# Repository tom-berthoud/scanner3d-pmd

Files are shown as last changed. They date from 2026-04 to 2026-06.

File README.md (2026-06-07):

# scanner3d-pmd

Scanner 3D à triangulation laser — Projet étudiant HEIG-VD, semestre 4, module PMD.

Le système capture des profils d'un objet en rotation sous un laser ligne, vu par deux caméras, reconstruit un nuage de points 3D, et exporte un fichier STL ou OBJ. Tout se passe dans une boîte fermée pilotée par un Raspberry Pi, accessible via une interface web ou un petit écran local.

## Rapport

La dernière version compilée du rapport est publiée automatiquement à chaque
push :
[télécharger le PDF](https://github.com/tom-berthoud/scanner3d-pmd/releases/download/rapport-latest/rapport-scanner3d-latest.pdf).

---

## Comment ça fonctionne

```
1. L'utilisateur pose l'objet sur le plateau et lance un scan
2. Le plateau tourne par pas réguliers sur 360° (nombre de photos = `scan.n_steps`, défaut 100)
3. À chaque pas : laser allumé → photo (les deux caméras) → laser éteint
4. Chaque image est analysée pour extraire la ligne laser verte
5. La triangulation géométrique convertit chaque ligne en profil 3D ; les deux
   vues réduisent les zones éclairées mais masquées
6. Tous les profils sont fusionnés en un nuage de points complet
7. Export en fichier STL ou OBJ, téléchargeable via l'interface web
```

**Géométrie de triangulation (deux caméras) :**
- Azimuts caméra/laser : ≈ −25° (caméra `right`) et +33° (caméra `left`)
- Élévations par rapport au plan XZ : ≈ −20° / +20°
- Plateau : centre à ≈ 400 mm des caméras (repère mm)
- Intrinsèques approximées (mode sans damier) : fx = fy ≈ 800 px @ 640×480 (facteur 1.25)

**Contraintes du projet :**
- Objets jusqu'à 150 × 150 × 150 mm
- Temps de scan < 10 min
- Prise en main < 10 min
- Budget ~300 CHF
- Boîte fermée (contrôle de la lumière ambiante)

---

## Structure du projet

```
scanner3d-pmd/
├── scanner/
│   ├── hardware/          Contrôle GPIO : moteur, laser, écran, caméra
│   │   └── mock.py        Simulation hardware (sans Raspberry Pi)
│   ├── acquisition/       Pipeline de capture image + sauvegarde frames
│   ├── calibration/       Calibration caméra et plan laser
│   ├── processing/        Extraction ligne laser + triangulation 3D
│   ├── reconstruction/    Fusion des profils en nuage de points
│   ├── export/            Génération STL / OBJ (Open3D Poisson)
│   ├── orchestration/     Machine d'états, boucle de scan
│   └── interface/         Serveur web Flask + affichage écran local
│       ├── templates/     Pages HTML (Jinja2)
│       └── static/        CSS, JS et assets vendorisés (vendor/ — hors-ligne)
├── config/                Paramètres YAML de scan et calibration
├── scripts/               Scripts utilitaires (ex. scanner-eng.sh)
├── tests/                 Tests unitaires et d'intégration
└── docs/                  Documentation, rapport et fichiers de fabrication
    ├── rapport/                 Rapport LaTeX (PDF compilé en Release)
    ├── cahier_des_charges/      Cahier des charges (LaTeX) + diagramme FAST
    ├── conception mécanique/    Modèles SolidWorks (.SLDPRT/.SLDASM),
    │                            DXF de découpe laser et STL d'impression 3D (CAD/)
    ├── schema/                  PCB et schéma électronique (KiCad)
    └── connection_procedure.md  Procédure de connexion PC ↔ Raspberry Pi
```

---

## Démarrage rapide

### Prérequis

- Python 3.11+
- Sur Raspberry Pi : Raspberry Pi OS 64-bit, deux caméras pour l'acquisition à
  double vue (Pi Camera Module 3 via CSI + caméra USB)

### Installation

```bash
git clone <repo-url>
cd scanner3d-pmd
python -m venv .venv && source .venv/bin/activate
pip install -r requirements.txt
```

> Les assets de l'interface (Bootstrap, polices, Three.js) sont **vendorisés**
> dans `scanner/interface/static/vendor/` : aucune connexion internet n'est
> requise au runtime, ni sur le PC, ni sur le Pi.

### Raccourcis (Makefile)

Un `Makefile` regroupe les opérations courantes. `make` (ou `make help`) liste
tout. Le Pi cible est `admin@192.168.55.1` (surchargeable :
`make ssh PI_HOST=…`).

| Catégorie | Commande | Effet |
|---|---|---|
| Local | `make install` / `make test` / `make test-fast` | venv + deps / tous les tests / tests rapides |
| Local | `make run` | lancer l'UI en **mode scan seul** (= prod) + navigateur |
| Local | `make run-full` | lancer l'UI avec **toutes les pages** (déverrouillé) + navigateur |
| Local | `make unlock-local` / `make lock-local` | (dé)verrouiller les pages techniques **en local** |
| Réseau | `make ping` / `make net-check` | Pi joignable / diagnostic réseau du Pi |
| Connexion | `make ssh` / `make open` | session SSH interactive / ouvrir l'UI du Pi dans le navigateur |
| Déploiement | `make pull` / `make pi-install` / `make pi-run` / `make pi-restart` | `git pull` / installer / lancer / redémarrer l'UI sur le Pi |
| Supervision | `make pi-status` / `make pi-logs` | état du service / logs sur le Pi |
| Ingénierie | `make unlock` / `make lock` / `make eng-status` | (dé)verrouiller les pages techniques **sur le Pi** (SSH) |

---

## Tester en local (sans Raspberry Pi — mode mock)

Le module `scanner/hardware/mock.py` simule tout le hardware et s'active
automatiquement si `gpiozero` n'est pas disponible (donc sur n'importe quel PC).

```bash
source .venv/bin/activate
python -m scanner.interface.web        # http://localhost:5000
```

Sur une machine de dev, débloquez d'emblée les pages d'ingénierie en mettant
`interface.engineering_force: true` dans `config/settings.yaml` (voir
[Mode ingénierie](#mode-ingénierie--accès-aux-pages-de-configuration)).

**Forme simulée** (`config/settings.yaml` → `camera.mock_shape`) : un seul
objet virtuel est disponible, un **`cube`** posé sur le plateau (demi-côté
30 mm, hauteur 60 mm).

Visualiser les images captées sans lancer un scan complet :
```
http://localhost:5000/preview                       ← slider interactif
http://localhost:5000/preview/frame?angle=0
http://localhost:5000/preview/extraction?angle=0    ← overlay ligne laser
```

**Tests :**
```bash
pytest tests/ -v                       # tous les tests
pytest tests/test_state_machine.py -v  # machine d'états seule (sans deps lourdes)
pytest tests/ -m integration           # tests nécessitant le vrai hardware
```

---

## Mise en production (Raspberry Pi)

1. **Connexion** PC ↔ Pi (Ethernet + SSH/HTTP) : voir
   [`docs/connection_procedure.md`](docs/connection_procedure.md).
2. **Installer** le projet et les dépendances (cf. *Installation* ci-dessus). Sur
   le Pi, `gpiozero` est présent → les vrais drivers GPIO sont utilisés
   automatiquement.
3. **Calibrer** la caméra et le plan laser au premier déploiement (cf.
   [Calibration](#calibration)).
4. **Lancer** le serveur :
   ```bash
   python -m scanner.interface.web     # écoute sur 0.0.0.0:5000
   ```
   L'interface est alors accessible depuis le PC sur `http://<ip-du-pi>:5000`.
5. **Écran tactile du Pi** : la page de scan (`/`) est elle-même conçue comme
   une console simplifiée plein écran (gros bouton de scan, navigation
   réduite). Il n'y a pas de mode kiosk séparé ; les pages techniques restent
   masquées tant que le
   [mode ingénierie](#mode-ingénierie--accès-aux-pages-de-configuration)
   n'est pas déverrouillé.

### Lancer automatiquement au démarrage (exemple systemd recommandé)

Le dépôt ne fournit pas de fichier de service, mais les cibles
`make pi-restart` / `pi-status` / `pi-logs` pilotent un service systemd nommé
**`scanner`**. Voici un exemple à créer sur le Pi
(`/etc/systemd/system/scanner.service`) :

```ini
[Unit]
Description=Scanner 3D web interface
After=network.target

[Service]
User=admin
WorkingDirectory=/home/admin/scanner3d-pmd
ExecStart=/home/admin/scanner3d-pmd/.venv/bin/python -m scanner.interface.web
Restart=on-failure

[Install]
WantedBy=multi-user.target
```
```bash
sudo systemctl enable --now scanner.service
```

> **Port web** : configurable via `interface.web_port` (défaut 5000) et
> `interface.web_host` (défaut `0.0.0.0`) dans `config/settings.yaml`.

---

## Mode ingénierie — accès aux pages de configuration

Pour rester léger en exploitation, **l'interface n'expose que le scan par
défaut**. Les pages techniques (Calibration, Extrinsèque, Cam Config, Manuel)
sont **verrouillées** : leurs onglets sont masqués et leurs routes (GET *et*
POST, donc les actions matérielles laser/moteur comprises) redirigent vers
la page de scan. Il n'y a **aucun mot de passe web** à gérer.

Un développeur, déjà connecté en SSH au Pi, les déverrouille avec le script
fourni :

```bash
# Depuis le PC, en une commande (équivalents : make unlock / lock / eng-status) :
ssh admin@<ip-du-pi> '~/scanner3d-pmd/scripts/scanner-eng.sh on'     # déverrouille
ssh admin@<ip-du-pi> '~/scanner3d-pmd/scripts/scanner-eng.sh off'    # reverrouille
ssh admin@<ip-du-pi> '~/scanner3d-pmd/scripts/scanner-eng.sh status' # état courant
```

- Le déverrouillage est pris en compte **immédiatement** (pas de redémarrage).
- Le verrou repose sur un **fichier sentinelle** (`interface.engineering_unlock_file`,
  défaut `/tmp/scanner-engineering.unlock`). Comme il vit dans `/tmp`, le Pi
  **se reverrouille automatiquement au redémarrage** (sûr en prod).
- Sur une machine de dev, `interface.engineering_force: true` débloque tout sans
  script.

---

## Interface web — caractéristiques

- **Thème clair** responsive, lisible sur PC comme sur le petit écran tactile du
  Pi. La page de scan est pensée comme une console plein écran ; la mise en page
  s'adapte à la largeur (desktop, mobile, petit écran tactile).
- **Hors-ligne** : tous les assets (Bootstrap, icônes, polices, Three.js) sont
  servis localement depuis `static/vendor/` et mis en cache long par le
  navigateur — démarrage rapide même sans internet.
- **Temps réel** : progression du scan poussée par Server-Sent Events ; aperçus
  caméra en flux JPEG à faible latence (polling auto-réamorcé pour ne pas
  saturer le Pi, qualité d'aperçu réduite vs. captures de calibration).
- **Viewer 3D** intégré (Three.js) pour visualiser le nuage / maillage exporté.

## Interface web — routes disponibles

🔒 = nécessite le [mode ingénierie](#mode-ingénierie--accès-aux-pages-de-configuration) déverrouillé.

| Route | Méthode | Description |
|---|---|---|
| `/` | GET | Page principale — statut + viewer 3D |
| `/scan/start` | POST | Démarre un scan (thread background) |
| `/scan/reset` | POST | Réinitialise l'état du scan (retour à `IDLE`) |
| `/scan/status` | GET | JSON : état, progression, dernier fichier |
| `/scan/stream` | GET | Server-Sent Events pour mises à jour en temps réel |
| `/scan/artifacts` | GET | Liste les fichiers produits (nuage, maillage…) |
| `/scan/artifact/<kind>` | GET | Récupère un artefact précis par type |
| `/scan/download` | GET | Télécharge le dernier fichier STL/OBJ |
| `/scan/frame/latest` | GET | Dernière image capturée (JPEG, avec overlay) |
| `/scan/frame/<n>` | GET | Image du pas n |
| `/preview` | GET | Visualisation interactive du mock caméra |
| `/preview/frame?angle=<rad>` | GET | Image brute à l'angle donné |
| `/preview/extraction?angle=<rad>` | GET | Image avec ligne laser détectée |
| `/usb/drives`, `/usb/export` | GET/POST | Liste / copie des fichiers vers une clé USB |
| 🔒 `/calibration` | GET | Page de calibration (caméra + plan laser, par caméra) |
| 🔒 `/calibration/camera/run` | POST | Calcule la calibration intrinsèque (après captures) |
| 🔒 `/calibration/laser/run` | POST | Calcule le plan laser (après captures) |
| 🔒 `/extrinsics` | GET | Réglage de la pose caméra (extrinsèques) |
| 🔒 `/camera-config` | GET | Configuration caméra (format, exposition…) |
| 🔒 `/manual` | GET | Commande manuelle (laser, moteur) |
| 🔒 `/manual/laser` | POST | Active/désactive le laser |
| 🔒 `/manual/motor` | POST | Fait avancer le moteur manuellement |
| 🔒 `/manual/safe-off` | POST | Coupe laser + moteur (arrêt sécurisé) |

> Les pages techniques (`/calibration`, `/extrinsics`, `/camera-config`,
> `/manual`) exposent aussi des sous-routes de session, capture et application
> non listées ici.

---

## Calibration

Le montage utilise **deux caméras** (`left` et `right`). Avant le premier scan
sur le vrai hardware, chacune doit être calibrée :

1. **Caméra** (intrinsèques) — matrice et distorsion, par caméra.
2. **Plan laser** — équation du plan laser dans le repère de chaque caméra.

Tout se fait depuis l'interface web **`/calibration`** (en mode ingénierie), qui
guide chaque étape (session, captures, calcul). Les résultats sont écrits dans
`config/`.

**Mode sans damier** : pour se passer de la calibration caméra par damier, mettez
`calibration.use_checkerboard: false` dans `config/settings.yaml`. Le système
utilise alors des intrinsèques approximées, déduites de la résolution et de
`calibration.approx_focal_scale`.

**Fichiers de configuration clés :**

| Fichier | Contenu |
|---|---|
| `config/settings.yaml` | Configuration globale : caméras, scan, calibration, interface |
| `config/camera_intrinsics_{left,right}.yaml` | Matrice caméra + distorsion, par caméra |
| `config/laser_plane_{left,right}.yaml` | Plan laser par caméra (gitignorés : propres au montage) |
| `config/platform.yaml` | Axe de rotation et pas/tour du plateau |
| `config/*.example.yaml` | Gabarits d'exemple versionnés (à copier puis calibrer) |

---

## Documentation technique

- **[`docs/rapport/`](docs/rapport/)** — Rapport complet : architecture, conception
  mécanique et électronique, chaîne logicielle, résultats. Document de référence.
- **[`docs/connection_procedure.md`](docs/connection_procedure.md)** — Connexion
  PC ↔ Raspberry Pi (Ethernet, SSH, HTTP).
- **`docs/schema/`** — Schéma et PCB KiCad (+ export `Schema connecteurs PCB.png`).
- **`docs/conception mécanique/CAD/`** — Modèles SolidWorks, DXF de découpe laser
  et STL d'impression 3D.

---

## Sécurité laser

Le laser est un laser ligne vert VLM-520-56 LPO-D45-F40 (520 nm, angle 45°, focale 40 mm).

- Désactivé par défaut au démarrage
- S'éteint automatiquement en cas d'erreur (état `ERROR`)
- Ne jamais regarder directement dans le faisceau
- La boîte doit être fermée pendant le scan

---

## Équipe

Projet à 5, HEIG-VD, module PMD — 2026

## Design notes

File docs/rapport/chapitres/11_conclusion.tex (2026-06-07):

\section{Conclusion}

Ce projet aboutit à un scanner 3D autonome capable d'enchaîner les opérations
qui étaient initialement étudiées séparément: rotation de la pièce, acquisition
de la ligne laser, triangulation, fusion des profils et génération d'un
maillage exploitable. L'intérêt principal du prototype ne réside donc pas
uniquement dans la reconstruction d'une forme, mais dans l'intégration d'une
chaîne complète autour d'un Raspberry Pi, avec une interface accessible hors
ligne et des mécanismes de sécurité actifs.

Le cycle complet dure environ 8 minutes et le coût réellement engagé est de
133,83\,CHF. Ces résultats montrent qu'une solution de numérisation à bas coût
peut être réalisée avec des composants accessibles tout en respectant les
contraintes principales du cahier des charges. Le caisson fermé, l'interlock et
l'arrêt logiciel du laser participent directement à la fiabilité d'utilisation
du système.

Le passage d'une à deux caméras a constitué l'évolution technique la plus
importante du projet. Il améliore la couverture des pièces complexes, mais
introduit aussi une dépendance plus forte à la calibration extrinsèque et au
regroupement des nuages. Le pipeline répond à ce compromis par une calibration
commune et un ajustement automatique des poses. Les résultats obtenus
restituent les géométries générales et donnent des dimensions proches des
références sur les axes $X$ et $Y$, avec des écarts généralement de l'ordre de
$\pm 2$\,mm.

\begin{table}[H]
  \centering
  \small
  \begin{tabular}{@{}p{2.1cm}p{7.1cm}p{5.2cm}@{}}
    \toprule
    \textbf{Réf.} & \textbf{Objectif} & \textbf{Statut} \\
    \midrule
    O1 (E1, E3) & Scan automatisé d'un objet jusqu'à $150^3$\,mm & Atteint, volume utile testé \\
    O2 (E6) & Export STL ou OBJ & Atteint \\
    O3 (B4) & Cycle inférieur à 10\,min & Atteint, environ 8\,min \\
    O4 (E7) & Prise en main et autonomie & Atteint \\
    O5 (E16) & Dépenses inférieures à 300\,CHF & Atteint, 133,83\,CHF \\
    O6 (E17--E19) & Sécurité utilisateur & Boîte fermée, laser classe 1M et interlock testés \\
    O7 (E5) & Retour visuel & Interface web opérationnelle; écran local non activé dans la configuration \\
    O8 (E10, E11) & Commande web ou USB & Atteint \\
    O9 (E24) & Précision et répétabilité & Environ $\pm 2$\,mm sur $X$ et $Y$; axe $Z$ non validé \\
    O10 (E21) & Encombrement et masse & Encombrement atteint; masse non relevée \\
    O11 (E23) & Périmètre géométrique défini & Maintenu \\
    \bottomrule
  \end{tabular}
  \caption{Bilan des objectifs du cahier des charges.}
  \label{tab:revue-obj}
\end{table}

Les essais ont volontairement privilégié le fonctionnement et la robustesse du
cycle sur plusieurs géométries plutôt qu'une validation métrologique complète.
La précision suivant l'axe $Z$ reste moins satisfaisante et la répétabilité
doit encore être caractérisée sur des pièces étalons. L'étude de la propagation
des erreurs entre le plan laser, les poses des caméras et la triangulation
constitue ainsi la prochaine étape logique du développement.

Une autre évolution pertinente serait de proposer deux stratégies
d'acquisition. Un mode utilisant uniquement la caméra supérieure simplifierait
le traitement des pièces entièrement visibles et éviterait une fusion inutile.
Le mode à deux caméras resterait réservé aux géométries présentant davantage
d'occultations. Ce choix adaptatif permettrait de rechercher la meilleure
qualité de reconstruction sans imposer systématiquement la complexité maximale
du pipeline.

Le prototype constitue finalement une base fonctionnelle et évolutive plutôt
qu'une simple démonstration de triangulation. Il valide l'architecture générale
du scanner et identifie clairement le travail restant pour passer d'un système
capable de reconstruire des objets à un véritable instrument de mesure.

% ---- Signatures -----------------------------------------------
\subsection*{Signatures}

\newcommand{\signature}[3][2cm]{%
  \begin{minipage}[b]{0.3\textwidth}
    \centering
    \\[-10pt]
    \rule{0.85\textwidth}{0.4pt}\\[2pt]
    {\small #3}
  \end{minipage}%
}
\newcommand{\signaturevide}[1]{%
  \begin{minipage}[b]{0.3\textwidth}
    \centering
    \vspace*{2cm}\par
    \rule{0.85\textwidth}{0.4pt}\\[2pt]
    {\small #1}
  \end{minipage}%
}

\vspace{1cm}
\noindent
\signature[1.6cm]{signatureLuc.jpg}{Luc Marchand}\hfill
\signature[1.15cm]{signatureTim.jpeg}{Tim Stamm}\hfill
\signature[1.6cm]{signatureJason.png}{Jason Weber}

\vspace{1.6cm}
\noindent\hspace*{0.175\textwidth}%
\signature{signaturehadrien.jpg}{Hadrien Fuentes}%
\hspace{0.05\textwidth}%
\signature{signaturetom.jpg}{Tom Berthoud}\hfill

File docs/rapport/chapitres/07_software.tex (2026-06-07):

\section{Logiciel et traitement}

\subsection{Architecture}

Le logiciel Python sépare le matériel, la calibration, l'acquisition, le
traitement, la reconstruction, l'export, l'orchestration et l'interface. Les
modules échangent des images, des paramètres de calibration, des profils 3D et
des états explicites.

\begin{figure}[H]
  \centering
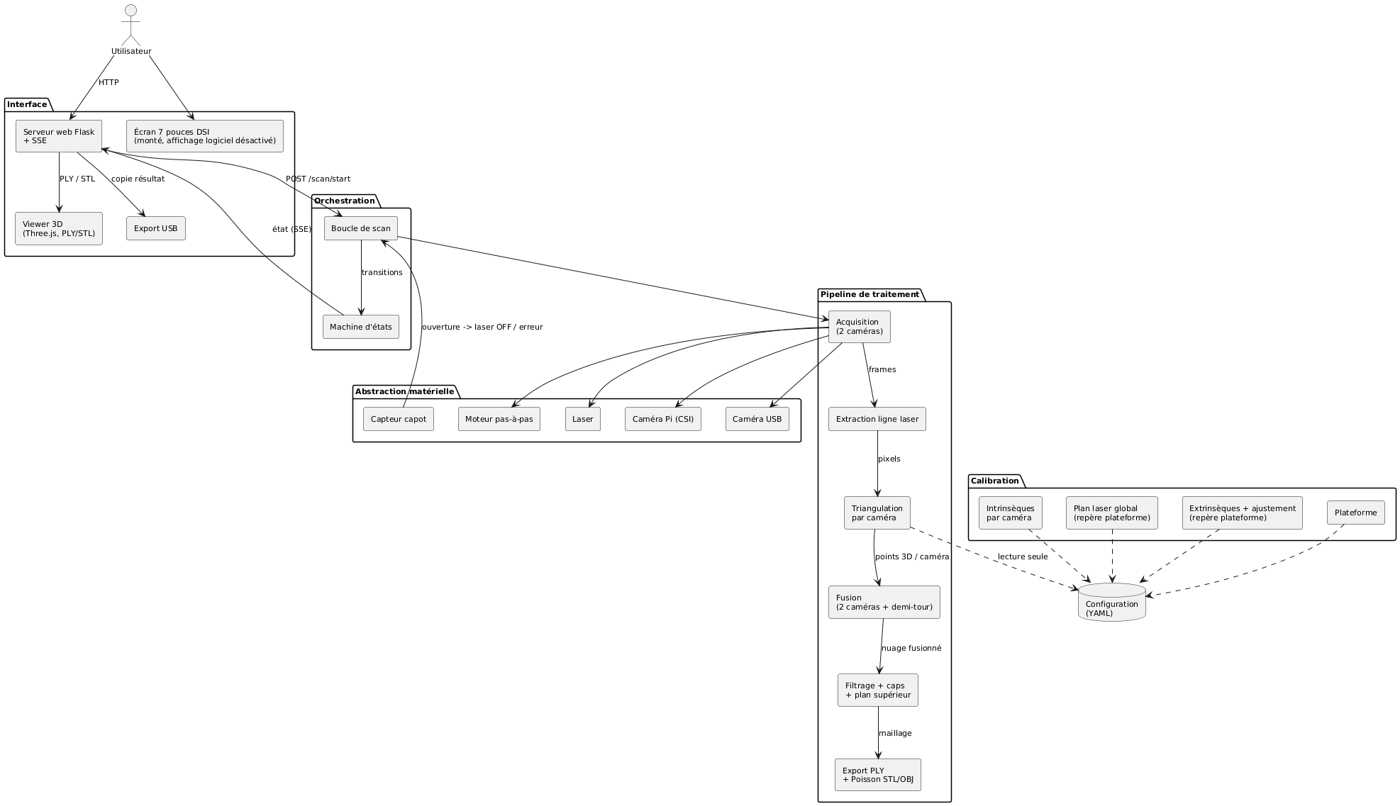
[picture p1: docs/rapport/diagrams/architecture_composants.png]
  
  \caption{Architecture logicielle et flux de données.}
  \label{fig:archi-composants}
\end{figure}

\begin{table}[H]
  \centering
  \small
  \begin{tabular}{@{}p{3.4cm}p{10.6cm}@{}}
    \toprule
    \textbf{Module} & \textbf{Responsabilité active} \\
    \midrule
    \texttt{hardware} & Caméras Pi/USB, moteur, laser et capteur de porte. \\
    \texttt{acquisition} & Rotation, contrôle de porte, laser et captures séquentielles. \\
    \texttt{calibration} & Intrinsèques, plan laser global et extrinsèques. \\
    \texttt{processing} & Extraction de ligne et triangulation vers le repère plateforme. \\
    \texttt{reconstruction} & Fusion, filtrage, détection de plan et caps. \\
    \texttt{export} & Nuages PLY et maillages Poisson STL. \\
    \texttt{orchestration} & Pipeline complet et machine d'états. \\
    \texttt{interface} & Flask, SSE, viewer Three.js, calibration et export USB. \\
    \bottomrule
  \end{tabular}
  \caption{Responsabilités des modules logiciels.}
  \label{tab:modules}
\end{table}

\subsection{Géométrie et calibration}

Chaque pixel détecté définit un rayon dans le repère de sa caméra. Les
intrinsèques corrigent la projection et la distorsion; les extrinsèques
transforment ensuite ce rayon dans le repère plateforme. Son intersection avec
le plan laser global donne un point 3D, qui est enfin déroté selon l'angle du
plateau.

\begin{figure}[H]
  \centering
  \resizebox{0.62\linewidth}{!}{\input{schemas/vue_dessus.tex}}
  \caption{Schéma de principe de la disposition des caméras autour du plan laser, vue de dessus.}
  \label{fig:geo-triangulation}
\end{figure}

Les paramètres utilisés par le code sont:

\begin{itemize}
  \item une calibration intrinsèque par caméra, obtenue avec un damier OpenCV;
  \item un plan laser commun exprimé dans le repère plateforme;
  \item une pose extrinsèque par caméra, définie par sa position et ses angles;
  \item l'axe de rotation et son origine dans le repère plateforme.
\end{itemize}

\begin{figure}[H]
  \centering
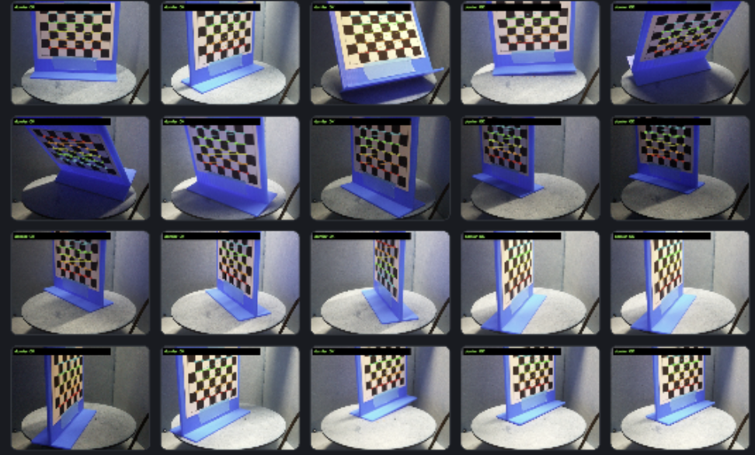
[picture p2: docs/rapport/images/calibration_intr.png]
  
  \caption{Images du damier utilisées pour la calibration intrinsèque. Les
  positions et orientations variées permettent d'estimer les paramètres
  optiques et la distorsion de la caméra.}
  \label{fig:calibration-intrinseque}
\end{figure}

Les azimuts retenus, environ $-25^\circ$ pour la caméra Pi et $+33^\circ$ pour
l'Arducam, sont issus de la calibration et d'essais visant un bon regroupement
des deux nuages de points. Ils définissent les poses initiales. Lors du
traitement, l'option active \texttt{auto\_cheat\_extrinsics} ajuste les deux
poses autour de ces valeurs afin de réduire la distance entre les nuages. Les
fichiers de calibration sont lus pendant le scan; ils ne sont pas modifiés par
le pipeline.

\begin{figure}[H]
  \centering
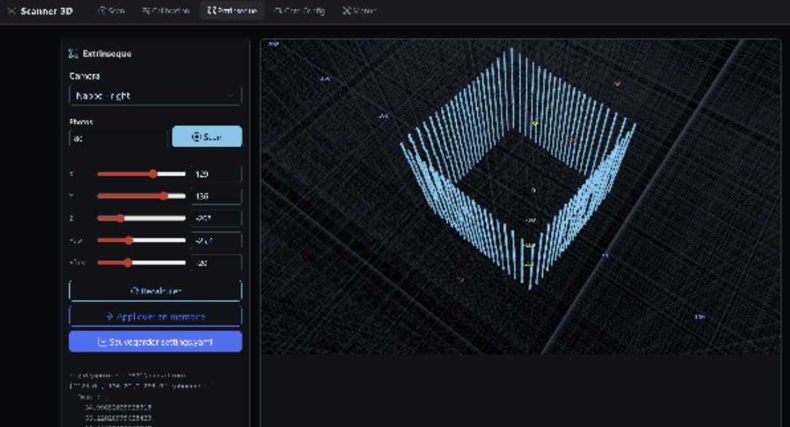
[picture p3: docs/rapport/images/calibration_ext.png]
  
  \caption{Interface de calibration extrinsèque. Le nuage reconstruit permet
  d'observer l'effet des paramètres de pose et de contrôler le regroupement
  des profils dans le repère plateforme.}
  \label{fig:calibration-extrinseque}
\end{figure}

\subsection{Acquisition}

La configuration active demande 100 positions sur un tour. Le moteur comporte
200 pas physiques par tour et le driver utilise 16 micro-pas, soit 3200
micro-pas. Chaque acquisition est donc séparée de 32 micro-pas, ou
$3{,}6^\circ$.

Les résolutions de capture sont configurables et correspondent aux images
natives demandées aux pilotes. La configuration active utilise
$640\times480$ pour la Pi Camera et $1920\times1080$ en YUYV pour l'Arducam
USB. 

Avant le scan, une boucle ajuste séparément l'exposition des caméras. Elle
capture trois angles par itération, mesure la largeur médiane des pixels verts
dépassant le seuil et vise une largeur de 6 pixels, avec une tolérance de
1 pixel. L'exposition reste bornée entre 200 et 60\,000\,$\mu$s.

Pour chaque position, la séquence active est:

\begin{enumerate}
  \item vérifier que le capot est fermé;
  \item avancer le moteur de 32 micro-pas;
  \item allumer le laser et vérifier à nouveau le capot;
  \item capturer successivement la caméra Pi et la caméra USB;
  \item éteindre le laser et sauvegarder les aperçus JPEG.
\end{enumerate}

L'extinction est également exécutée dans les chemins d'erreur.

\subsection{Extraction et triangulation}

L'extraction lit le canal vert des images BGR et applique un seuil propre à
chaque caméra. Les zones qui ne peuvent pas contenir de mesure utile sont
retirées par des masques rectangulaires ou polygonaux. Le traitement inspecte
une colonne sur une et une ligne sur deux pour la Pi Camera; pour l'Arducam, il
inspecte une colonne sur trois et une ligne sur quatre. Cet échantillonnage
réduit le nombre de pixels testés sans redimensionner les images.

\begin{figure}[H]
  \centering
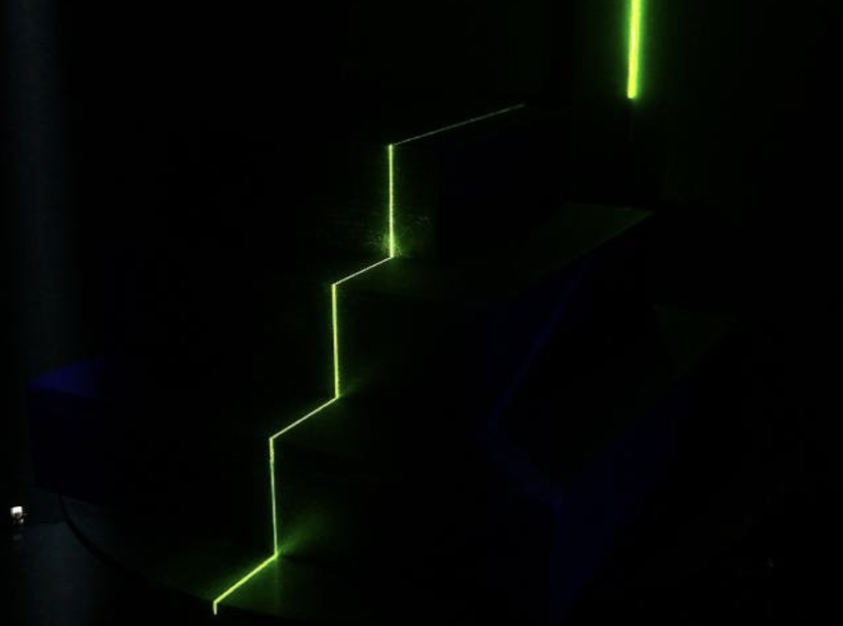
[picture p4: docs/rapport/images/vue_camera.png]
  
  \caption{Vue réelle d'une caméra pendant l'acquisition. La ligne laser verte
  apparaît sur les arêtes successives de la pièce et constitue le signal
  extrait par le traitement.}
  \label{fig:vue-camera-laser}
\end{figure}

Pour chaque ligne échantillonnée qui contient des pixels actifs, l'algorithme
calcule la moyenne de leurs colonnes. Les pas et les décalages
d'échantillonnage sont ensuite réappliqués: les coordonnées produites restent
donc exprimées dans le repère de l'image native, soit $640\times480$ ou
$1920\times1080$. Une détection est rejetée si elle contient moins de quatre
lignes.

La triangulation utilise alors les intrinsèques de la caméra pour former les
rayons, les extrinsèques pour les exprimer dans le repère plateforme et le
plan laser global pour calculer leurs intersections. L'angle courant du
plateau ramène enfin chaque profil dans l'orientation de référence. Les deux
caméras produisent ainsi des points directement comparables dans un même
repère.

\subsection{Fusion et reconstruction}

Les profils opposés d'un demi-tour peuvent être rapprochés et moyennés lorsque
leur distance est inférieure à la tolérance configurée. Pour une même
position, les profils des deux caméras sont projetés sur leur axe principal:
les zones proches sont moyennées, tandis que les points divergents sont
conservés pour ne pas écraser une géométrie visible par une seule caméra.

Les profils fusionnés sont concaténés puis filtrés avec un KDTree SciPy. Un
filtre statistique rejette les points dont la distance moyenne aux voisins est
anormalement grande. Le logiciel exporte les nuages de chaque caméra et le
nuage combiné au format PLY.

Le maillage final est produit par Open3D:

\begin{enumerate}
  \item dédoublonnage et estimation des normales;
  \item orientation cohérente des normales;
  \item reconstruction de Poisson, profondeur 8 par défaut;
  \item détection éventuelle du plan supérieur depuis la caméra droite;
  \item découpe du maillage par ce plan et fermeture de la coupe;
  \item ajout de caps plats et nettoyage du maillage;
  \item export STL selon la configuration.
\end{enumerate}

\begin{figure}[H]
  \centering
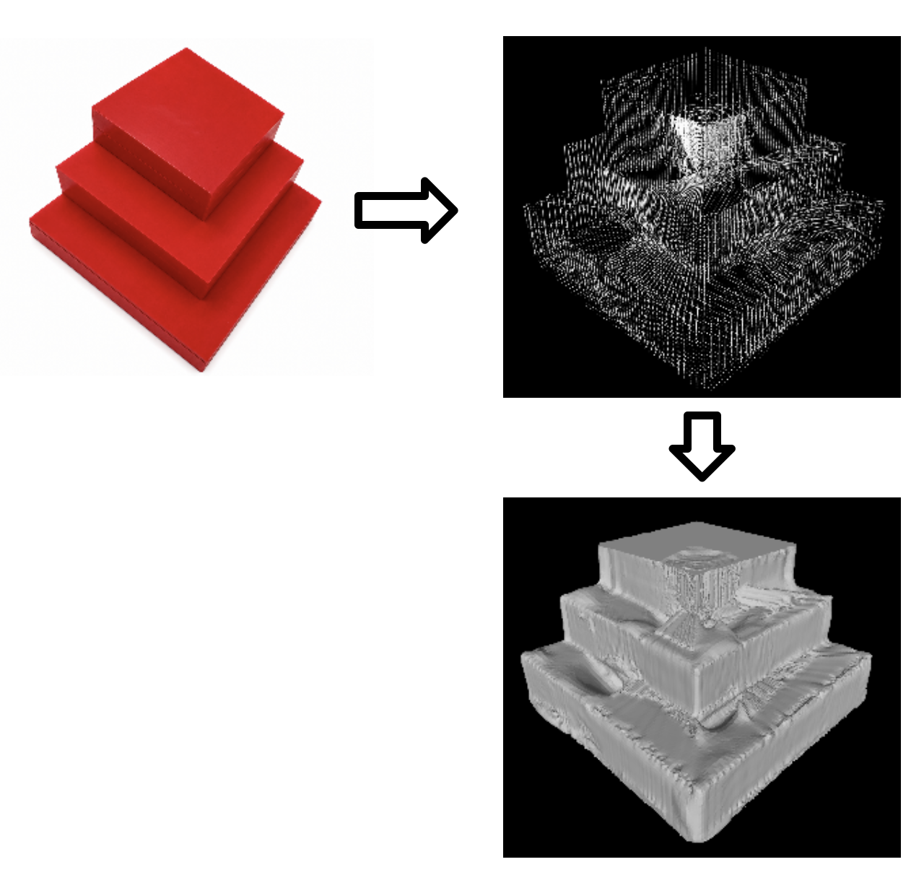
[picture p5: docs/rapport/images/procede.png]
  
  \caption{Étapes principales de la reconstruction: pièce réelle, nuage de
  points obtenu après triangulation et fusion, puis maillage de surface
  exportable.}
  \label{fig:procede-reconstruction}
\end{figure}

Ces opérations améliorent la fermeture du maillage.

\subsection{Orchestration et sécurité}

La machine d'états couvre l'attente et la calibration
(\texttt{IDLE}, \texttt{CALIBRATING}), le cycle de scan
(\texttt{SCANNING}, \texttt{PROCESSING}, \texttt{EXPORTING}) et ses issues
(\texttt{COMPLETE}, \texttt{ERROR}). Elle refuse les transitions non prévues.

\begin{figure}[H]
  \centering
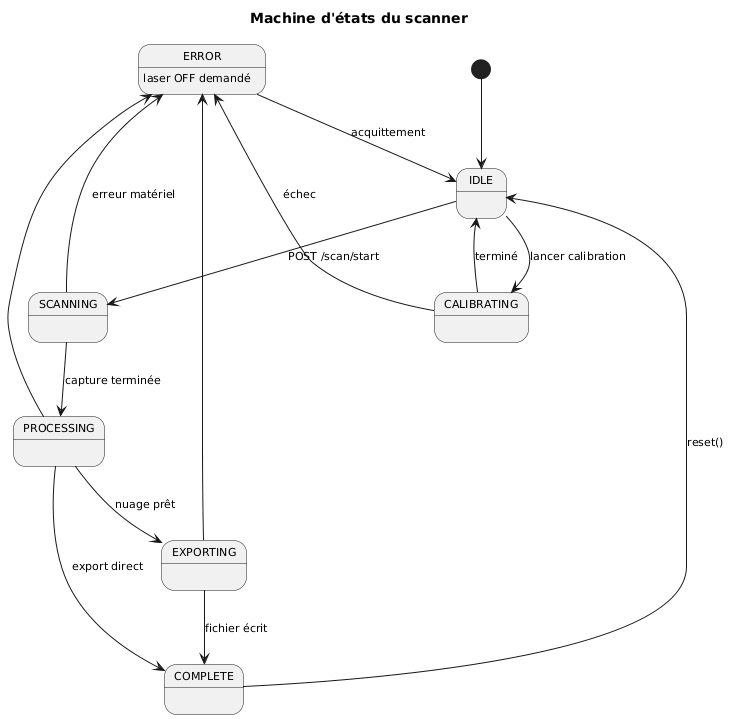
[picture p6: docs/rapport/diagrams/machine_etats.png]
  
  \caption{Machine d'états du scanner.}
  \label{fig:fsm}
\end{figure}

Le serveur empêche deux scans concurrents. Lors d'une erreur, l'orchestration
éteint le laser avant de demander l'état \texttt{ERROR}. L'interlock vérifie
le capot avant et juste après la mise sous tension du laser. Un watchdog
logiciel interroge également le capteur toutes les 100\,ms et force
l'extinction du laser lorsque le capot est ouvert. Les commandes manuelles
disposent également d'une action de mise en sécurité.

\subsection{Interface}

L'interface Flask permet de lancer ou réinitialiser un scan, suivre sa
progression par SSE, consulter les captures, afficher les nuages PLY et le
maillage, télécharger le résultat et le copier sur une clé USB. Les
bibliothèques front-end sont servies localement.

Le mode ingénierie ajoute les pages de calibration, de réglage des caméras,
d'extrinsèques et de commande manuelle. Ces outils sont masqués dans le mode
d'utilisation courant.

\begin{figure}[H]
  \centering
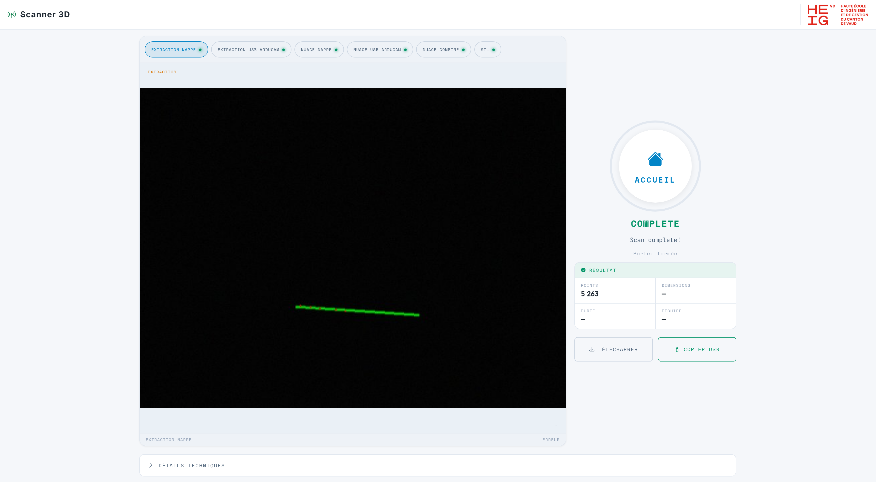
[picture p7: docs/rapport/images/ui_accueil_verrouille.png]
  
  \caption{Page principale de l'interface web en mode utilisateur.}
  \label{fig:interface}
\end{figure}

\subsection{Intégration au Raspberry Pi et services}

Le logiciel est installé sur Raspberry Pi OS 64 bits dans le dépôt du projet.
Ses dépendances Python sont isolées dans un environnement virtuel
\texttt{.venv}. Le point d'entrée de production est la commande
\texttt{python -m scanner.interface.web}, exécutée avec l'interpréteur de cet
environnement. Au démarrage, l'application charge
\texttt{config/settings.yaml}, initialise les pilotes matériels, construit la
machine d'états et démarre le watchdog du capteur de capot.

Le lancement automatique est assuré par une unité \texttt{systemd} nommée
\texttt{scanner}. Elle démarre l'application après l'initialisation du réseau,
utilise le dossier du projet comme répertoire de travail et relance le
processus en cas d'échec. L'activation dans la cible
\texttt{multi-user.target} rend l'interface disponible après le démarrage du
Raspberry Pi. Le service est redémarré et inspecté avec \texttt{systemctl};
ses journaux sont accessibles avec \texttt{journalctl}. Le \texttt{Makefile}
regroupe ces opérations dans les commandes \texttt{pi-restart},
\texttt{pi-status} et \texttt{pi-logs}.

Le serveur Flask écoute sur toutes les interfaces réseau
(\texttt{0.0.0.0}) au port 5000. Il sert localement les pages, les feuilles de
style, Three.js et les autres ressources front-end, ce qui permet une
utilisation hors ligne. Sur la liaison Ethernet directe, le Raspberry Pi
utilise l'adresse fixe \texttt{192.168.55.1}. Son service DHCP attribue
automatiquement une adresse au PC connecté, qui accède ensuite à l'interface
sur \texttt{http://192.168.55.1:5000}.

Une demande de scan crée un thread de travail séparé: le serveur reste
disponible pour transmettre l'état, la progression et les artefacts par SSE
pendant que l'orchestration pilote le matériel et le traitement.

En exploitation, seules les fonctions utilisateur sont accessibles. Les pages
de calibration, d'extrinsèques, de configuration des caméras et de commande
manuelle sont protégées par un verrou logiciel. Le script
\texttt{scripts/scanner-eng.sh} crée ou supprime un fichier sentinelle dans
\texttt{/tmp}; la modification est prise en compte sans redémarrer le service.
Comme ce fichier temporaire disparaît au redémarrage du Raspberry Pi,
l'interface revient automatiquement au mode utilisateur.

\subsection{Limites logicielles}

\begin{itemize}
  \item la fusion dépend fortement des extrinsèques et de leur ajustement;
  \item le seuillage du canal vert peut retenir des surfaces vertes ou des
        reflets dans les zones non masquées;
  \item Poisson extrapole une surface dans les zones peu observées;
  \item les cavités invisibles pour le laser et les deux caméras restent
        impossibles à reconstruire.
\end{itemize}

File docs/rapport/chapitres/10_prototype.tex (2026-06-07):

\section{Prototype et résultats}

\subsection{État livré}

Le prototype réunit la boîte, le plateau motorisé, le laser, les deux
caméras, le PCB de commande, le capteur de capot, l'écran tactile et
l'interface web. Le pipeline réel produit des nuages PLY intermédiaires et un
maillage STL.

\begin{figure}[H]
  \centering
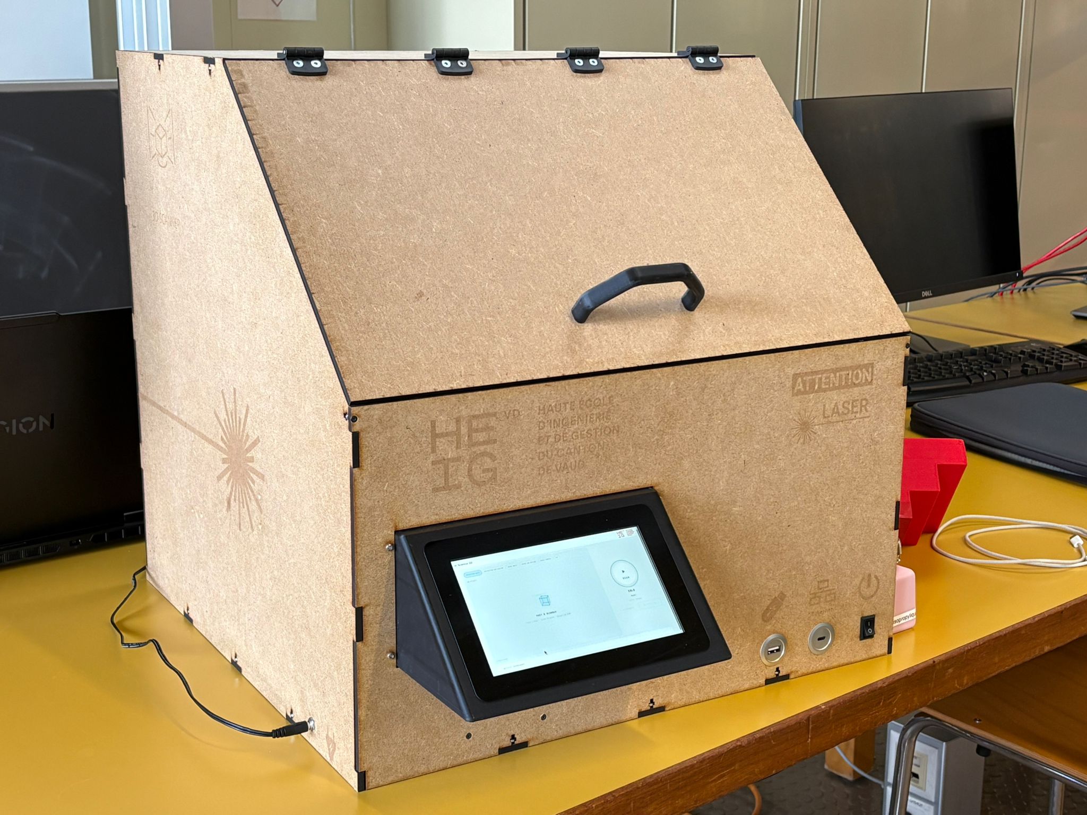
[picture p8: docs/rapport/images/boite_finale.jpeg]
  
  \caption{Vue extérieure du prototype final assemblé.}
  \label{fig:boite-finale}
\end{figure}

\begin{table}[H]
  \centering
  \small
  \begin{tabular}{@{}p{4.1cm}p{3cm}p{7cm}@{}}
    \toprule
    \textbf{Fonction} & \textbf{Statut} & \textbf{Justification} \\
    \midrule
    Acquisition à deux caméras & Démontrée & Pipeline matériel et captures par position. \\
    Interlock et arrêt laser & Testés & Capteur monté, contrôles avant activation et surveillance périodique à 100~ms. \\
    Extraction et triangulation & Démontrées & Nuages PLY produits par caméra. \\
    Fusion et maillage & Démontrés & Export Poisson STL disponible. \\
    Interface et export USB & Démontrés & Routes web, viewer et copie USB implémentés. \\
    \bottomrule
  \end{tabular}
  \caption{État des fonctions et validations.}
  \label{tab:maturite}
\end{table}

\subsection{Résultats}
\label{sec:prototype-resultats}

Un cycle complet, depuis le lancement jusqu'à l'export, a été chronométré à
environ 8 minutes. L'objectif O3 est donc atteint pour la configuration testée.
Les deux points de vue récupèrent davantage de zones sur les formes anguleuses
qu'une acquisition mono-caméra.

\begin{figure}[H]
  \centering
  \begin{minipage}{0.45\linewidth}
    \centering
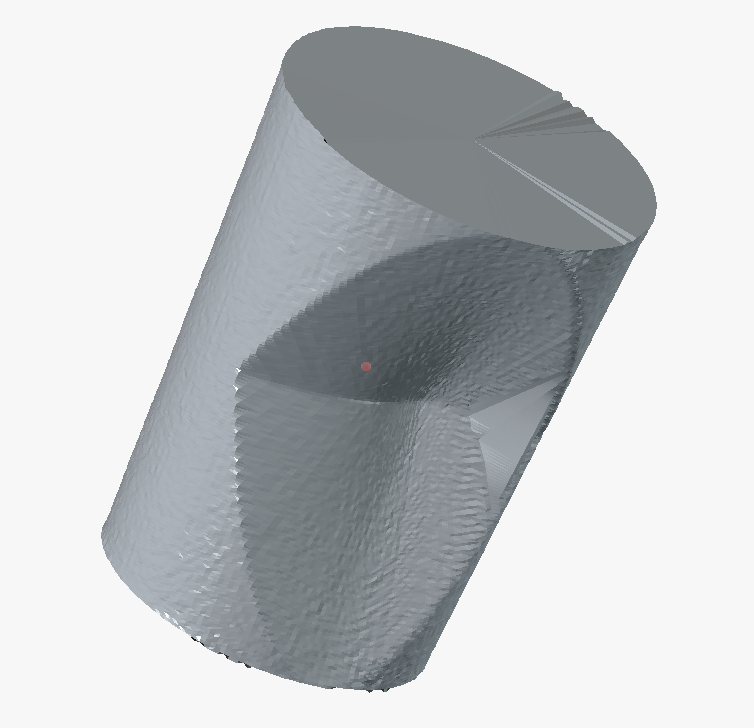
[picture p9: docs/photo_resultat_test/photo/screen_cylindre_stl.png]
    
    \\\small (a) Maillage d'un cylindre.
  \end{minipage}\hfill
  \begin{minipage}{0.45\linewidth}
    \centering
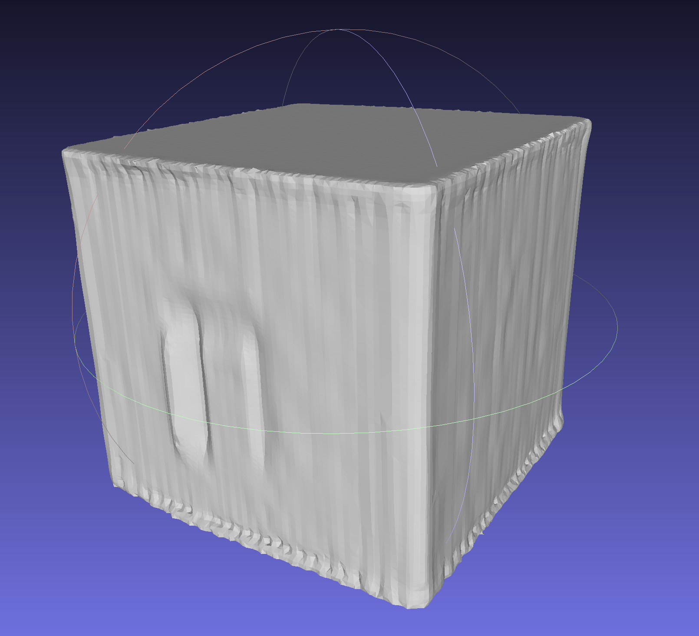
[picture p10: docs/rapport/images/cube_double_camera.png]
    
    \\\small (b) Résultat à deux caméras sur un cube.
  \end{minipage}
  \caption{Exemples de reconstructions produits par le pipeline final.}
  \label{fig:resultats-scans}
\end{figure}

\begin{figure}[H]
  \centering
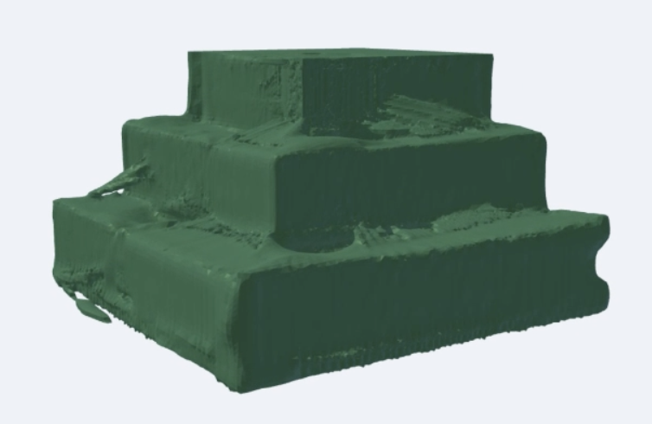
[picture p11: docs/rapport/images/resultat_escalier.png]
  
  \caption{Maillage obtenu pour la pièce en escalier. Les différents niveaux
  sont reconnaissables; des irrégularités restent visibles près des arêtes et
  dans certaines zones moins bien observées.}
  \label{fig:resultat-escalier}
\end{figure}

Les comparaisons dimensionnelles réalisées sur les pièces reconstruites
montrent une précision satisfaisante dans le plan horizontal: les dimensions
relevées suivant les axes $X$ et $Y$ restent généralement dans un intervalle
d'environ $\pm 2$\,mm par rapport aux dimensions de référence. L'échelle
verticale est en revanche moins fidèle et présente des écarts plus importants
sur l'axe $Z$. Cette différence semble liée à la plus forte sensibilité de la
hauteur reconstruite à l'ensemble de la chaîne géométrique, notamment au
réglage des poses, au plan laser et à la visibilité des surfaces horizontales.
Les essais disponibles ne permettent toutefois pas d'isoler une cause unique.
Le scanner restitue donc correctement la forme générale et les dimensions
dans le plan, tandis que la mesure suivant $Z$ demande encore une calibration
plus approfondie avant de pouvoir être considérée comme métrologique.

\begin{table}[H]
  \centering
  \begin{tabular}{@{}p{6cm}p{4cm}p{3.5cm}@{}}
    \toprule
    \textbf{Indicateur} & \textbf{Résultat} & \textbf{Cible} \\
    \midrule
    Cycle complet & $\approx$\,8\,min & $\leq 10$\,min \\
    Export STL & Produit & Obligatoire \\
    Coût réellement engagé & 133,83\,CHF & $\leq 300$\,CHF \\
    Dimensions extérieures & $500\times500\times500$\,mm & $\leq 500^3$\,mm \\
    \bottomrule
  \end{tabular}
  \caption{Résultats disponibles à la livraison.}
  \label{tab:perf-attendues}
\end{table}

\subsection{Limites}

La qualité dépend du réglage optique, des masques et de l'ajustement
extrinsèque. Les surfaces brillantes, très sombres, vertes ou cachées peuvent
dégrader l'extraction.

L'amélioration de la précision suivant l'axe $Z$ constitue un axe prioritaire
pour la suite du projet. Un travail complémentaire devra chercher à identifier
l'origine des écarts observés, en étudiant notamment la calibration du plan
laser, les poses extrinsèques des caméras et la propagation des erreurs dans la
triangulation. Une campagne de mesures sur plusieurs pièces étalons permettrait
ensuite de quantifier séparément la précision et la répétabilité sur les trois
axes.

Un mode de scan utilisant uniquement la caméra supérieure pourrait également
être avantageux pour les pièces simples et entièrement visibles depuis ce
point de vue. Il éviterait alors le regroupement de deux nuages et réduirait la
sensibilité du résultat aux extrinsèques relatives des caméras. L'acquisition
à deux caméras resterait toutefois essentielle pour les pièces plus complexes,
présentant des faces masquées ou des zones insuffisamment observées par une
seule caméra. Une évolution de l'interface pourrait ainsi permettre de choisir
le mode d'acquisition selon la géométrie de la pièce.

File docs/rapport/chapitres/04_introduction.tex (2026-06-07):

\section{Introduction}

\subsection{Contexte}

Ce projet, réalisé dans le cadre de l'unité d'enseignement \filiere{} à la
HEIG-VD, répond à un besoin du MakeLab: disposer d'un scanner 3D pédagogique,
modifiable et reproductible avec les moyens de fabrication disponibles sur
place. Un tel équipement complète les imprimantes 3D et les outils de
conception assistée par ordinateur. Il permet notamment de numériser une forme
existante, d'en conserver une représentation numérique ou de produire une
base géométrique pour une nouvelle conception.

Le projet porte sur l'ensemble de la chaîne, depuis le dispositif mécanique
jusqu'au fichier exploitable. Il comprend la boîte, le plateau rotatif,
l'éclairage laser, les caméras, l'électronique de commande, le logiciel de
calibration, l'acquisition, la reconstruction et l'interface utilisateur. Le
prototype doit rester compréhensible par les utilisateurs du MakeLab et
modifiable par une équipe qui reprendrait le projet.

\subsection{Principe de mesure}

L'objet à numériser est placé sur un plateau rotatif dans une boîte fermée. Un
laser ligne vert projette un plan lumineux sur sa surface. La déformation de
la ligne observée dans une image dépend de la position du point éclairé. Après
calibration des caméras et du plan laser, l'intersection entre le rayon associé
à un pixel et ce plan fournit un point tridimensionnel.

Le plateau présente successivement les différentes faces de l'objet. À chaque
position, deux caméras situées de part et d'autre du laser capturent un profil.
Les points sont ramenés dans le repère du plateau en tenant compte de l'angle
de rotation, puis fusionnés. Un filtrage limite les points aberrants et une
reconstruction de surface produit le maillage exporté. La seconde caméra a été
ajoutée après les premiers essais à une caméra afin de réduire les zones
éclairées mais masquées depuis un seul point de vue.

Cette méthode reste soumise à des limites géométriques. Une surface doit être
éclairée par le laser et visible par une caméra; une cavité fermée ou une forte
contre-dépouille ne peut donc pas être reconstruite. Les matériaux
transparents, très réfléchissants ou fortement absorbants peuvent également
dégrader la détection de la ligne.

\subsection{État de l'art}

Les scanners commerciaux à lumière structurée offrent de bonnes performances,
mais dépassent le budget du projet ou reposent sur des logiciels propriétaires.
FabScanPi~\cite{fabscanpi} et Ciclop/Horus~\cite{ciclop} démontrent qu'une
triangulation laser à plateau rotatif est réalisable à faible coût. Le projet
s'en distingue surtout par l'acquisition à deux caméras, choisie pour réduire
les occultations, et par une interface web utilisable hors ligne.

Plusieurs familles de techniques sont couramment utilisées pour numériser un
objet. La photogrammétrie reconstruit sa géométrie à partir de nombreuses
photographies et de points visuels communs. Elle demande peu de matériel
spécialisé, mais dépend fortement de la texture de la surface et du calcul de
mise en correspondance. La lumière structurée projette un motif connu et
mesure sa déformation; elle permet une acquisition dense, au prix d'une
optique et d'une calibration plus complexes. Les capteurs de profondeur
intègrent directement la mesure, mais offrent moins de liberté sur la
géométrie et la chaîne de traitement.

La triangulation par laser ligne constitue un compromis adapté au projet. Son
principe est observable, ses composants sont accessibles et chaque étape peut
être étudiée séparément. La boîte réduit l'influence de la lumière ambiante
et protège l'utilisateur, tandis que le plateau permet de couvrir le pourtour
de l'objet sans déplacer les caméras. Le choix de deux caméras ne supprime pas
les limitations optiques, mais augmente les chances qu'une zone éclairée soit
vue par au moins l'un des capteurs.

\subsection{Cahier des charges et objectifs}

Les objectifs issus du cahier des charges~\cite{cdc} sont résumés dans la
table~\ref{tab:objectifs}. Un objectif n'est déclaré atteint dans ce rapport que
s'il est démontré par le prototype ou par une mesure disponible.

Le cahier des charges impose un volume utile de
$150\times150\times150$\,mm, un cycle inférieur à 10 minutes et une prise en
main inférieure à 10 minutes. Le résultat doit être exportable au minimum au
format STL ou OBJ. Le système doit fournir un retour visuel, communiquer par
USB ou par interface web, rester dans un budget cible de 300\,CHF et enfermer
la zone de mesure. La sécurité vis-à-vis du laser et des parties mobiles est
une exigence de conception, pas une option de performance.

\begin{table}[H]
  \centering
  \small
  \begin{tabular}{@{}p{1.2cm}p{12.5cm}@{}}
    \toprule
    \textbf{Réf.} & \textbf{Objectif} \\
    \midrule
    O1 & Numériser automatiquement un objet jusqu'à $150\times150\times150$\,mm (E1, E3). \\
    O2 & Produire un fichier STL ou OBJ (E6). \\
    O3 & Réaliser un cycle complet en moins de 10\,minutes (besoin utilisateur B4 du cahier des charges). \\
    O4 & Permettre une prise en main en moins de 10\,minutes et 90\,\% de scans sans assistance sur 10 essais (E7). \\
    O5 & Limiter les dépenses du projet à 300\,CHF (E16). \\
    O6 & Protéger l'utilisateur du laser et des parties mobiles (E17, E18, E19). \\
    O7 & Fournir un retour visuel de l'état du système (E5). \\
    O8 & Commander le scanner par interface web ou USB en cinq actions au plus (E10, E11). \\
    O9 & Atteindre une erreur moyenne $\leq 2$\,mm et une répétabilité $\leq 1$\,mm (E24). \\
    O10 & Respecter un encombrement $\leq 500^3$\,mm et une masse $\leq 15$\,kg (E21). \\
    O11 & Traiter les objets sans cavité fermée ni contre-dépouille supérieure à $45^\circ$ (E23). \\
    \bottomrule
  \end{tabular}
  \caption{Objectifs mesurables du projet.}
  \label{tab:objectifs}
\end{table}

\subsection{Démarche et organisation}

Le projet a été conduit sur 16 semaines. Le planning final, reproduit en
annexe~\ref{annexe:planning}, totalise 361 heures. Le travail a progressé par
itérations: définition de l'architecture, réalisation des sous-systèmes,
intégration, puis essais du cycle complet. Les premières acquisitions à une
caméra ont mis en évidence les occultations et conduit au montage à deux
caméras. Les calibrations et les paramètres de traitement ont ensuite été
ajustés sur le prototype assemblé.

\begin{table}[H]
  \centering
  \begin{tabular}{@{}p{4.5cm}p{10cm}@{}}
    \toprule
    \textbf{Membre} & \textbf{Responsabilité principale} \\
    \midrule
    Tom Berthoud    & Architecture logicielle, triangulation et coordination. \\
    Jason Weber     & Interface utilisateur, reconstruction et export. \\
    Luc Marchand    & Électronique, alimentation et sécurité. \\
    Hadrien Fuentes & Câblage, acquisition et essais. \\
    Tim Stamm       & Conception mécanique, boîtier et plateau rotatif. \\
    \bottomrule
  \end{tabular}
  \caption{Répartition principale du travail.}
  \label{tab:roles}
\end{table}

\subsection{Livrables et structure du rapport}

Le livrable comprend le prototype assemblé, son logiciel, les configurations
de calibration, les schémas et fichiers de fabrication, le présent rapport et
des exemples de scans. L'interface doit permettre d'exécuter le cycle sans
manipuler directement le code, de suivre sa progression et de récupérer le
résultat.

L'ensemble des fichiers sources (code, fichiers de fabrication mécaniques et
électroniques, et ce rapport) est disponible sur le dépôt public du projet :
\url{https://github.com/tom-berthoud/scanner3d-pmd}.

La suite du rapport présente d'abord la conception mécanique, puis la
conception électrique et électronique. Le chapitre logiciel décrit la
calibration, l'acquisition, la triangulation, la fusion et l'export réellement
utilisés. Le prototype et les résultats mesurés sont ensuite confrontés au
cahier des charges.

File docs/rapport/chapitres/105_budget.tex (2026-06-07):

\section{Budget et coûts}

\subsection{Méthode}

Le budget du projet est présenté selon deux notions distinctes, conformément
à la grille d'estimation fournie au lancement du projet :

\begin{itemize}
  \item l'\textbf{estimation du coût du prototype} : ce que coûterait la
        réalisation si l'ensemble du travail était facturé aux tarifs
        horaires d'un bureau d'ingénierie (main d'\oe uvre, machines de
        fabrication et pièces achetées) ;
  \item le \textbf{coût réel pour l'école} : la dépense effectivement engagée.
        Les heures de travail des étudiants ne sont pas facturées, et les
        moyens de fabrication (impression 3D, découpe laser) ainsi qu'une
        partie des composants proviennent du stock du MakeLab. Le coût réel
        se résume donc aux pièces effectivement commandées.
\end{itemize}

Les tarifs horaires retenus sont ceux de la grille du cours : ingénieur HES
à 150\,CHF/h, mécanicien à 80\,CHF/h, impression 3D à 40\,CHF/h et découpe
laser à 50\,CHF/h.

\subsection{Estimation du coût du prototype}

Le temps de travail provient du planning final (\autoref{annexe:planning}) :
\textbf{361 heures} consommées au total. La répartition retenue distingue
les heures d'ingénierie (logiciel, électronique, électrique, gestion de
projet) des heures de mécanique (conception, fabrication et montage,
réalisées par le pôle ROCM). Les durées d'impression 3D et de découpe laser
correspondent au temps machine, estimé séparément.

\begin{table}[H]
  \centering
  \begin{tabular}{@{}p{5cm}r r r@{}}
    \toprule
    \textbf{Poste} & \textbf{Quantité} & \textbf{Tarif} & \textbf{Total} \\
    \midrule
    Ingénieur HES        & 314\,h & 150\,CHF/h & 47\,100\,CHF \\
    Mécanicien           & 47\,h  & 80\,CHF/h  & 3\,760\,CHF \\
    Impression 3D        & 15\,h  & 40\,CHF/h  & 600\,CHF \\
    Découpe laser        & 2\,h   & 50\,CHF/h  & 100\,CHF \\
    Pièces achetées      & ---    & ---        & $\approx$\,500\,CHF \\
    \midrule
    \textbf{Total estimé} & & & $\approx$\,\textbf{52\,060\,CHF} \\
    \bottomrule
  \end{tabular}
  \caption{Estimation du coût de développement du prototype, tarifs HES.}
  \label{tab:budget-estimation}
\end{table}

L'essentiel du coût estimé provient de la main d'\oe uvre d'ingénierie : le
projet est avant tout un travail de conception et de développement
logiciel. Le coût matériel reste marginal devant le coût en temps.

\subsection{Pièces achetées — nomenclature}

La nomenclature ci-dessous distingue les composants \emph{commandés} pour le
projet des composants \emph{issus du stock} du MakeLab, dont le prix est
estimé au prix de marché pour l'estimation du prototype.

\begin{table}[H]
  \centering
  \begin{tabular}{@{}p{6.5cm}p{2.2cm}r p{2.3cm}@{}}
    \toprule
    \textbf{Composant} & \textbf{Origine} & \textbf{Prix} & \textbf{Réf.} \\
    \midrule
    Laser ligne vert VLM-520-56 (520\,nm) & Commandé    & 77.08\,CHF & DigiKey \\
    2$\times$ caméra USB OV9726 (720p)\textsuperscript{*} & Commandé & 17.60\,CHF & Galaxus \\
    Adaptateur Gigabit Ethernet USB-C      & Commandé    & 8.90\,CHF  & Galaxus \\
    Adaptateur encastrable USB-C BU-BU     & Commandé    & 15.90\,CHF & Galaxus \\
    Adaptateur de panneau USB-A f-f        & Commandé    & 13.70\,CHF & Galaxus \\
    Contribution climatique                & Commandé    & 0.65\,CHF  & Galaxus \\
    \midrule
    Raspberry Pi 4 Model B                 & Stock       & $\approx$\,65\,CHF & --- \\
    Pi Camera Module 3                     & Stock       & $\approx$\,35\,CHF & --- \\
    Caméra USB Arducam IMX586              & Prêt        & $\approx$\,50\,CHF & --- \\
    Raspberry Pi Touch Display 2           & Stock       & $\approx$\,70\,CHF & --- \\
    Moteur pas à pas NEMA 17 (17HS3401)    & Stock       & $\approx$\,12\,CHF & --- \\
    Driver moteur DM320T                   & Stock       & $\approx$\,45\,CHF & --- \\
    Alimentation 24\,V 24\,W (Hama)        & Stock       & $\approx$\,25\,CHF & --- \\
    Convertisseur 24$\to$5\,V LM2596       & Stock       & $\approx$\,4\,CHF  & --- \\
    Interrupteur, connecteurs, capteur capot & Stock     & $\approx$\,15\,CHF & --- \\
    PCB dédié (fabrication)                & Stock       & $\approx$\,15\,CHF & --- \\
    Matière (PLA, panneau MDF, visserie)   & Stock       & $\approx$\,30\,CHF & --- \\
    \midrule
    \textbf{Total estimé (prix de marché)} & & \textbf{$\approx$\,500\,CHF} & \\
    \bottomrule
  \end{tabular}
  \caption{Nomenclature des pièces et estimation des prix. Les prix « Stock » sont estimés au prix de marché ; ils n'entrent pas dans le coût réel pour l'école.}
  \label{tab:budget-bom}
\end{table}

\textsuperscript{*}\,Les deux caméras USB OV9726 ont bien été commandées et
payées (elles figurent donc dans le coût réel), mais n'ont \emph{pas} pu être
utilisées : leur angle d'ouverture, non précisé à la commande, s'est avéré trop
étroit ($\approx 40^\circ$) pour couvrir la zone de scan. La seconde caméra du
montage final est une \textbf{Arducam IMX586} prêtée par l'école, qui n'a donc
engendré aucune dépense.

\subsection{Coût réel pour l'école}

Les heures de travail ne sont pas facturées et les moyens de fabrication du
MakeLab ne génèrent pas de dépense supplémentaire. Le coût réellement engagé
se limite aux deux commandes passées pour le projet.

\begin{table}[H]
  \centering
  \begin{tabular}{@{}p{8cm}r@{}}
    \toprule
    \textbf{Commande} & \textbf{Montant (TTC)} \\
    \midrule
    DigiKey --- laser ligne VLM-520-56          & 77.08\,CHF \\
    Galaxus --- caméras USB et adaptateurs       & 56.75\,CHF \\
    \midrule
    \textbf{Coût réel total}                     & \textbf{133.83\,CHF} \\
    \bottomrule
  \end{tabular}
  \caption{Coût réel engagé pour le projet.}
  \label{tab:budget-reel}
\end{table}

Le coût réel de \textbf{133.83\,CHF} respecte largement l'objectif
budgétaire \textbf{O5} (\(\leq\) 300\,CHF). Même en valorisant l'ensemble
des composants au prix de marché ($\approx$\,500\,CHF,
\autoref{tab:budget-bom}), le coût matériel reste du même ordre de grandeur
que l'objectif, l'écart provenant essentiellement de l'écran tactile et du
Raspberry Pi.

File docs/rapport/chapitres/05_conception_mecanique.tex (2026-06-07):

\section{Conception mécanique}

\subsection{Architecture mécanique}

Le scanner se présente sous la forme d'une boîte fermée de dimensions
extérieures $500\times500\times500$\,mm (exigence \textbf{E21}). L'architecture
est pensée pour une intégration directe dans l'environnement du MakeLab
de la HEIG-VD (FC3) et pour limiter l'accès utilisateur aux pièces
mobiles ainsi qu'au faisceau laser.

Le prototype final comprend une boîte découpée au laser et refermable, un
plateau rotatif découpé au laser, un moteur pas-à-pas, un support de laser
imprimé en 3D et deux supports de caméra imprimés en 3D. Les deux
caméras sont montées de part et d'autre du laser, placé dans un angle de
la boîte, avec des azimuts d'environ $-25^\circ$ et $+33^\circ$. Cette
disposition résulte de la calibration et des essais de regroupement des
nuages de points (FT4 / E12). L'ensemble a d'abord été modélisé en CAO
avant fabrication (figure~\ref{fig:cao}) : la boîte et le plateau rotatif
destinés à la découpe laser, ainsi que les supports laser, caméra et
nappe destinés à l'impression 3D.

\begin{figure}[H]
  \centering
  \begin{minipage}{0.48\linewidth}
    \centering
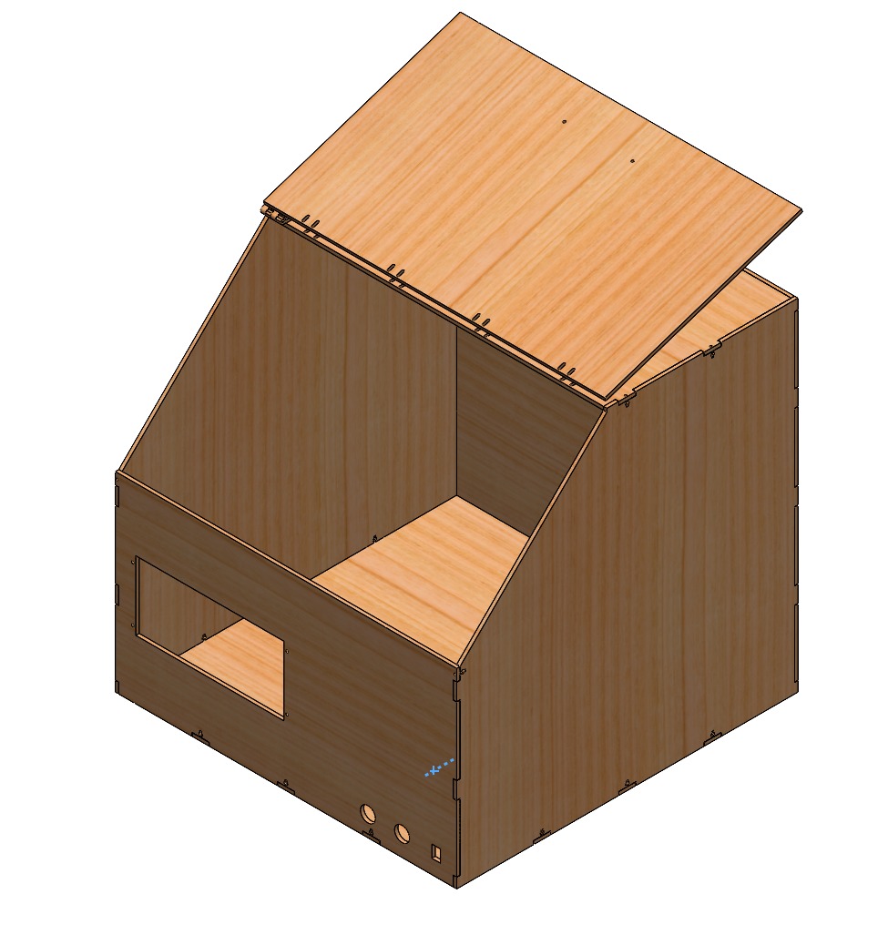
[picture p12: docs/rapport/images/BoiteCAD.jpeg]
    
    \\\small (a) Boîte complète
  \end{minipage}\hfill
  \begin{minipage}{0.48\linewidth}
    \centering
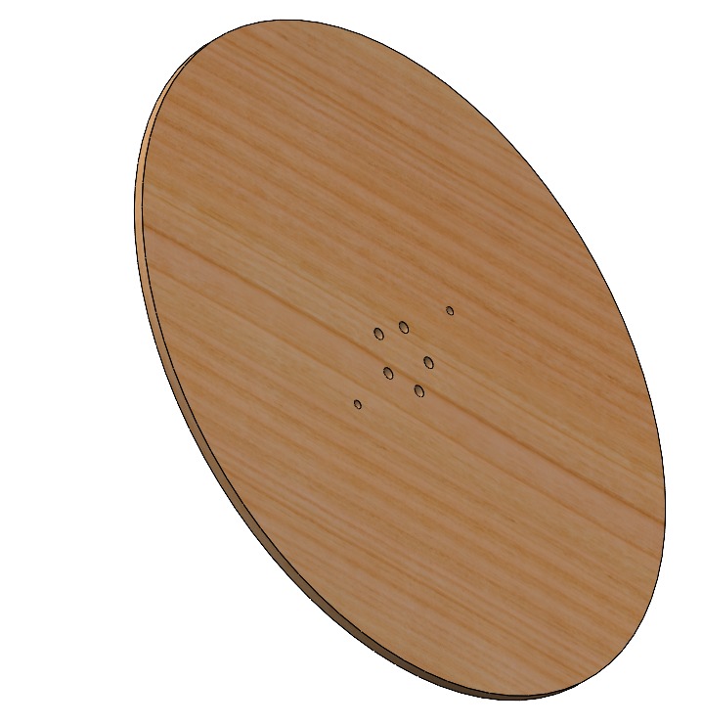
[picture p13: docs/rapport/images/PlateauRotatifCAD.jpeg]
    
    \\\small (b) Plateau rotatif
  \end{minipage}

  \vspace{1em}

  \begin{minipage}{0.48\linewidth}
    \centering
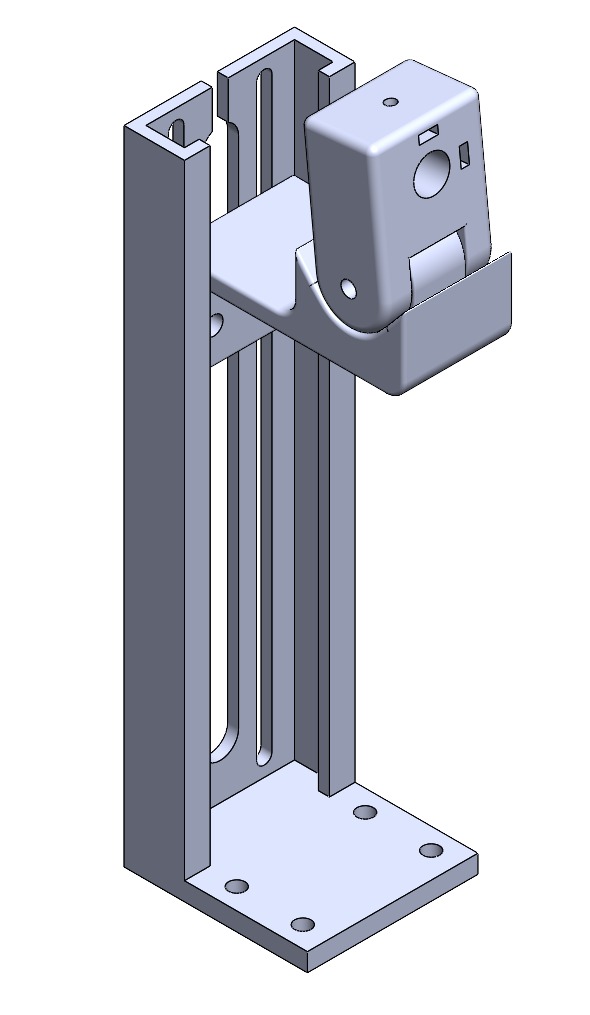
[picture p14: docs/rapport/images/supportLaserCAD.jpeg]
    
    \\\small (c) Support laser
  \end{minipage}\hfill
  \begin{minipage}{0.48\linewidth}
    \centering
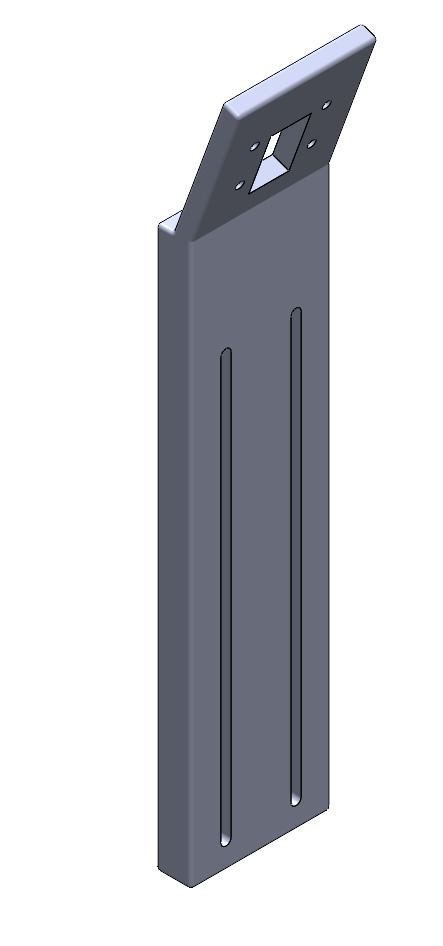
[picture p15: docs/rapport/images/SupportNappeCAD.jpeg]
    
    \\\small (d) Support Raspberry Pi caméra
  \end{minipage}
  \caption{Modèles CAO du scanner : boîte et plateau rotatif (découpe laser),
  supports laser et caméra (impression 3D).}
  \label{fig:cao}
\end{figure}

\begin{figure}[H]
  \centering
  \begin{minipage}{0.48\linewidth}
    \centering
    
    \\\small (a) Vue extérieure du prototype final.
  \end{minipage}\hfill
  \begin{minipage}{0.48\linewidth}
    \centering
    
    \\\small (b) Vue intérieure avec les deux caméras et le laser.
  \end{minipage}
  \caption{Prototype mécanique : boîte MDF découpée laser, plateau rotatif, supports caméras et laser imprimés en 3D.}
  \label{fig:proto-meca}
\end{figure}

Le système s'organise autour de trois sous-ensembles :

\begin{itemize}
  \item \textbf{Plateau rotatif motorisé} (FT7, \textbf{E15}) :
        support de l'objet à numériser, entraîné par un moteur
        pas-à-pas NEMA\,17. Le plateau est centré dans l'enceinte et
        son axe de rotation est aligné avec le plan de mesure défini
        par le laser et les caméras. Le plateau fonctionne pendant les
        cycles de scan.
  \item \textbf{Bâti de mesure} : supporte les deux caméras et le
        module laser ligne vert dans une géométrie fixe. Le laser est
        positionné dans un angle de la boîte et les caméras sont placées
        de part et d'autre de son plan.
        Les supports imprimés en 3D constituent une solution adaptée au
        projet : ils permettent de positionner rapidement les éléments
        optiques, d'itérer sur les angles et de rester compatibles avec
        les moyens de fabrication du MakeLab. Les supports définitifs
        sont stables et verrouillés après calibration.
  \item \textbf{Plaques en bois} : boîte fermable assurant le confinement
        mécanique et lumineux.
\end{itemize}

\subsection{Zone de scan et périmètre fonctionnel}

La zone utile est dimensionnée pour accueillir un objet maximal de
$150\times150\times150$\,mm (\textbf{E3}). La boîte a été dimensionnée
à $500\times500\times500$\,mm, résultant d'un compromis entre l'espace
nécessaire pour accueillir la pièce, les distances optiques requises
pour la triangulation, le placement des composants électroniques et la
contrainte de taille raisonnable pour le MakeLab (E21).

\subsection{Choix des matériaux et fabrication}

Le prototype utilise principalement deux types de matériaux et procédés de
fabrication :

\paragraph{Boîte et plateau rotatif (MDF)}
La boîte et le plateau rotatif sont réalisés en MDF (Medium Density
Fiberboard). Ce matériau a été retenu pour sa facilité d'usinage à la
découpe laser et sa rigidité suffisante. Le MDF présente également une bonne
opacité, contribuant à l'isolation lumineuse de la zone de scan
(FT1 / E9), et permet de minimiser les reflets et diffusions parasites
du faisceau laser lors du scan.

\paragraph{Supports caméra, laser, moteur et plateau rotatif (PLA imprimé en 3D)}
Ces supports sont fabriqués par impression 3D en PLA. Ce procédé permet une
fabrication rapide au MakeLab, un coût faible et une adaptation précise aux
composants retenus. Le PLA est inerte, non toxique (E17), léger et
suffisamment rigide pour les supports réalisés.

\subsection{Gravure et marquages}

La face avant de la boîte a été gravée au laser lors de la découpe des
panneaux MDF. Ces marquages, réalisés dans le même procédé que la
découpe, ne nécessitent aucune pièce supplémentaire et restent durables
dans le temps. Ils remplissent deux rôles : l'identification du projet et
le guidage de l'utilisateur.

\begin{itemize}
  \item \textbf{Logos} : le logo de la HEIG-VD est
        gravé sur la face avant afin d'identifier l'origine du projet.
  \item \textbf{Avertissement laser} : un pictogramme de danger laser est
        gravé pour signaler la présence du faisceau et compléter les
        mesures de sécurité (\textbf{E19}).
  \item \textbf{Bouton d'alimentation général} : un marquage indique le
        bouton de mise sous et hors tension de l'ensemble du système.
  \item \textbf{Emplacement de la clé USB} : un repère gravé indique
        l'endroit où insérer la clé USB pour récupérer les fichiers
        exportés.
  \item \textbf{Connexion au réseau} : un marquage indique l'adresse ou
        l'emplacement permettant de se connecter au réseau du scanner
        pour accéder à l'interface web.
\end{itemize}

Ces gravures rendent le prototype directement utilisable sans
documentation externe : l'utilisateur identifie d'un coup d'\oe il les
points d'interaction (alimentation, clé USB, réseau) ainsi que la
consigne de sécurité liée au laser.

\begin{figure}[H]
  \centering
  
  \caption{Face avant de la boîte avec les gravures laser : logos,
  avertissement laser et repères des points d'interaction.}
  \label{fig:gravure}
\end{figure}

\subsection{Dimensionnement et stabilité}

Les panneaux de la boîte sont assemblés par un système d'encoches et de
rainures par emboîtement, vu lors du cours ProFabMT 2026, garantissant
la rigidité de la structure et facilitant le montage et le démontage.
Le support du plateau rotatif assure la liaison entre le moteur et le
plateau via des inserts filetés, garantissant une fixation robuste et
démontable. La fixation au moteur est assurée par une vis sans tête et
un écrou. Les autres supports sont assemblés avec vis et écrou.

Le dimensionnement du plateau rotatif vise un couple suffisant pour
supporter un objet de masse modérée à vitesse lente. Le moteur NEMA\,17
sélectionné reste adapté aux essais actuels : aucun blocage majeur du
moteur ou du plateau n'a été observé pendant les scans réalisés.

La rigidité des supports caméra et laser est également critique. Une
variation de position ou d'angle modifie directement la calibration et
peut provoquer une erreur de triangulation. Les supports imprimés en 3D sont
stables et verrouillés après calibration.

\subsection{Sécurité mécanique}

Deux mesures principales assurent la protection de l'utilisateur :

\begin{itemize}
  \item \textbf{Confinement des pièces mobiles} (\textbf{E18}) :
        le plateau et le moteur sont placés dans une boîte fermée,
        limitant l'accès direct pendant un scan.
  \item \textbf{Confinement du laser} (\textbf{E19}) : la boîte
        refermable limite l'exposition directe au faisceau.
\end{itemize}

La fiche technique du fabricant identifie la variante LPO de la série
VLM-520-56 comme un produit de classe 1M~\cite{quarton_vlm52056}. Le
confinement reste nécessaire, notamment vis-à-vis de l'observation avec des
instruments optiques.

L'interlock de capot est monté et testé sur le prototype. Lorsque
l'ouverture du capot est détectée, le logiciel éteint le laser et
interrompt le scan.

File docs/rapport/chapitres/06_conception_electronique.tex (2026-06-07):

\newpage
\section{Conception électrique et électronique}
\label{sec:conception_electronique}

Cette section présente la conception et la réalisation des parties électrique et électronique du scanner 3D. 
L'objectif principal de cette architecture est d'assurer la distribution de l'alimentation électrique, de piloter les différents actionneurs avec précision et de centraliser l'acquisition des données des capteurs.
La démarche présentée va du choix des composants à leur intégration physique, en passant par la conception des schémas électriques et la réalisation de circuits imprimés dédiés, tout en intégrant les éléments de sécurité indispensables à l'utilisation du système.

\subsection{Choix des composants et spécifications}
\label{subsec:composants}

Le choix des composants électroniques a été principalement guidé par les spécifications techniques du cahier des charges (précision, dimension de la pièce, durée du scan) ainsi que par la disponibilité des pièces au sein du \textit{MakeLab} de la HEIG-VD, permettant ainsi d'optimiser les coûts et les délais de livraison.
Le tableau~\ref{tab:bom_finale} dresse l'inventaire complet du matériel sélectionné.

\begin{table}[H]
    \centering
    \begin{tabular}{l p{5.5cm} l}
        \toprule
        \textbf{Fonction} & \textbf{Composant / Référence} & \textbf{Interface} \\
        \midrule
        Unité centrale & Raspberry Pi 4 Model B & --- \\
        Acquisition optique (CSI) & Pi Camera Module 3 & Connecteur CSI \\
        Acquisition optique (USB) & Arducam IMX586 & Port USB 3.0 \\
        Éclairage structuré & Laser ligne vert VLM-520-56 LPO-D45-F40 & GPIO (via PCB) \\
        Actionneur rotatif & Moteur pas à pas NEMA 17 & Liaison mécanique \\
        Contrôle moteur & Driver industriel Leadshine DM320T & Signaux impulsionnels \\
        Interface utilisateur & Raspberry Pi Touch Display 2 (7 pouces) & Connecteur nappe DSI \\
        Alimentation principale & Bloc secteur 24\,Vdc (1\,A / 24\,W) & Connecteur DC \\
        Régulation logique & Convertisseur Buck DC-DC LM2596 (HW-411) & Ligne 5\,Vdc \\
        Sécurité physique & Interrupteur fin de course (125-250\,V) & Contact sec (GPIO) \\
        Mise sous tension & Interrupteur à bascule KCD1-101 & Ligne 24\,Vdc \\
        \bottomrule
    \end{tabular}
    \caption{Nomenclature et interfaces des composants électroniques du scanner 3D.}
    \label{tab:bom_finale}
\end{table}

\subsubsection{Unité de calcul et de traitement}
Le choix s'est porté sur un \textbf{Raspberry Pi 4 Model B}. 
Les tests préliminaires ayant démontré qu'une version antérieure (Raspberry Pi 3) offrait des performances CPU insuffisantes pour traiter les algorithmes de reconstruction 3D dans un temps acceptable, le modèle 4 s'est imposé. 
De plus, sa compatibilité native avec les modules caméras et l'écran tactile du MakeLab a facilité l'intégration logicielle.

\subsubsection{Système de double vision}
Afin de limiter les phénomènes d'occultation lors de la numérisation, deux caméras sont utilisées simultanément :
\begin{itemize}
    \item \textbf{Caméra principale :} Le module \textbf{Pi Camera Module 3} est connecté via la nappe CSI standard. Ce choix se justifie par sa résolution native et son angle d'ouverture parfaitement adaptés à la distance de focalisation du scanner.
    \item \textbf{Caméra secondaire :} Une caméra USB \textbf{Arducam IMX586} a été ajoutée. Fournie par l'intermédiaire de M. Maulaz, cette caméra présentait une résolution suffisante et un angle d'ouverture adapté pour capturer les zones d'ombre sous un autre axe, tout en étant immédiatement disponible.
\end{itemize}

\subsubsection{Laser lumineux}
Le choix de la source lumineuse s'est arrêté sur le laser
\textbf{VLM-520-56 LPO-D45-F40}. La fiche du fabricant classe la variante LPO
de cette série en classe 1M et indique une longueur d'onde comprise entre 515
et 530\,nm~\cite{quarton_vlm52056}. Cette émission verte correspond à une zone
de forte sensibilité du canal vert de la caméra, comme l'illustre la
figure~\ref{fig:sensibilite_spectrale}. Cette association fournit un contraste
élevé et facilite l'extraction logicielle de la ligne laser.

Le module utilise des lentilles en verre pour la collimation et la génération
de la ligne. Sa focalisation à 40\,cm est adaptée à la distance de travail du
scanner et permet d'obtenir une ligne suffisamment fine pour la détection.
\begin{figure}[H]
    \centering
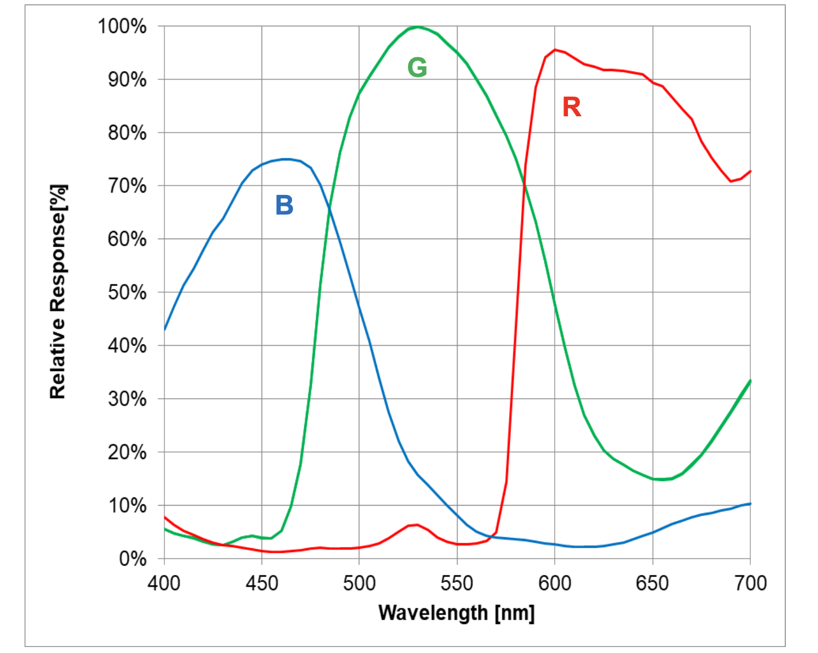
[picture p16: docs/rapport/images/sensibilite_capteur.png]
    
    \caption{Sensibilité spectrale par canal du capteur de la caméra (Doc. officielle Raspberry Pi).}
    \label{fig:sensibilite_spectrale}
\end{figure}

\subsubsection{Système de rotation et contrôle moteur}
Pour la partie motrice, le couple formé par le moteur \textbf{NEMA 17} et le driver \textbf{Leadshine DM320T} (disponibles au MakeLab) répond aux exigences de couple nécessaires pour faire tourner le plateau sans glissement, tout en offrant la précision angulaire requise grâce aux réglages des micro-pas sur le driver.

\subsubsection{Interface utilisateur (Écran tactile)}
L'affichage local est confié au \textbf{Raspberry Pi Touch Display 2} de 7 pouces. Sa diagonale offre une surface d'affichage idéale pour présenter l'ensemble des menus de contrôle et les retours d'état du scanner. La dalle tactile capacitive est d'une sensibilité suffisante pour assurer une navigation fluide à travers les différentes pages de l'interface utilisateur.

\subsubsection{Alimentation et organes de sécurité}
Le driver du moteur pas à pas nécessitant une tension élevée pour générer le couple nécessaire, le système est alimenté en \textbf{24\,Vdc} par un bloc secteur de 24\,W (1\,A). À partir de ce rail de puissance, un convertisseur abaisseur ajustable (\textit{Buck converter}) basé sur un \textbf{LM2596 (HW-411)} est employé pour abaisser la tension à 5\,Vdc afin d'alimenter proprement le Raspberry Pi, le laser et l'écran tactile. 

La mise sous tension générale est coupée mécaniquement par un interrupteur \textbf{KCD1-101}. Enfin, la détection de la fermeture de la porte est confiée à un interrupteur de fin de course compact (microswitch), faisant office de capteur de sécurité pour le capot.

\begin{figure}[H]
    \centering
    
    \caption{Vue d'ensemble des principaux composants électroniques assemblés dans le scanner 3D.}
    \label{fig:photo_composants}
\end{figure}

\subsection{Schématique et architecture électrique}
\label{subsec:schema_electrique}

L'architecture électrique du scanner 3D est structurée en deux étages distincts, répartis sur un schéma complet de deux pages (représentés par les figures~\ref{fig:sch_alim} et~\ref{fig:sch_rpi}). 
Cette organisation permet de séparer clairement la puissance de la logique de commande.

\subsubsection{Gestion de l'énergie et étage d'alimentation (Page 1)}

Le système est alimenté en périphérie par le bloc secteur délivrant une tension continue de 24\,Vdc. 
La distribution de cette énergie est configurée ainsi :
\begin{itemize}
    \item \textbf{Ligne de puissance :} La tension de 24\,Vdc traverse l'interrupteur principal \texttt{KCD1-101} pour sécuriser l'ensemble de la machine. Une fois l'interrupteur fermé, le rail 24\,Vdc alimente directement l'étage de puissance du driver de moteur pas à pas \texttt{DM320T}.
    \item \textbf{Ligne logique (Dérivation) :} En dérivation sur ce rail principal, le convertisseur Buck \texttt{LM2596} abaisse la tension à 5\,Vdc. Ce rail 5\,Vdc secondaire est envoyé vers le second étage pour alimenter les composants logiques.
    \item \textbf{Alimentation du Raspberry Pi :} Contrairement à une utilisation standard via le port USB-C, le 5\,Vdc régulé par le Buck est injecté directement sur les broches physiques (\textit{pins} GPIO) dédiées à l'alimentation du Raspberry Pi 4. Cette méthode permet de centraliser le câblage et d'éviter l'usage de connecteurs grand public.
\end{itemize}

\begin{figure}[H]
    \centering
    
    \caption{Schéma électrique — Page 1 : Étage d'alimentation générale et distribution de la puissance.}
    \label{fig:sch_alim}
\end{figure}

\subsubsection{Interconnexions de la logique et des actionneurs (Page 2)}

La seconde page du schéma centralise le Raspberry Pi 4, qui fait office de nœud de commande pour l'ensemble des périphériques.

\begin{itemize}
    \item \textbf{Commande du laser et commutation \textit{Low-Side} :} Le module laser \texttt{VLM-520} est alimenté par le rail 5\,Vdc issu du convertisseur Buck. Sa ligne de masse (0\,V) passe à travers le PCB MOSFET. Lorsque le GPIO du Raspberry Pi s'active, le transistor effectue une mise à la masse (\textit{pull to 0V}), fermant le circuit et allumant le laser.
    \item \textbf{Commande du driver moteur \texttt{DM320T} :} Les signaux de commande angulaire (\textit{Pulse}, \textit{Direction}, \textit{Enable}) utilisent le même principe de commutation par MOSFET tirant au 0\,V. Du côté du driver, les broches d'entrées optocouplées (\texttt{OPTO}) sont reliées en permanence au rail 5\,Vdc. Cette configuration garantit un signal net et franc pour le déclenchement des optocoupleurs internes du driver, tout en protégeant les sorties du Raspberry Pi. Les 4 fils de phase du moteur \texttt{NEMA 17} sont quant à eux raccordés directement sur les sorties de puissance du \texttt{DM320T}.
    \item \textbf{Boucle du capteur de capot :} Le microswitch de sécurité est câblé de manière directe et minimale. Un fil est connecté à une broche d'alimentation 3,3\,Vdc du Raspberry Pi, et le second retourne directement sur une broche GPIO configurée en entrée. L'état logique de la ligne permet ainsi de détecter l'ouverture de la porte. Le logiciel vérifie le capteur avant l'activation du laser et un watchdog le surveille toutes les 100\,ms pendant le fonctionnement.
    \item \textbf{Acquisition et affichage :} Le système de vision (nappe de la Pi Camera, câble de la caméra Arducam USB) ainsi que la nappe DSI de l'écran tactile de 7 pouces sont connectés directement sur leurs ports natifs respectifs du Raspberry Pi.
\end{itemize}

\subsubsection{Accessibilité externe et connectique de maintenance}

Pour permettre une utilisation et une maintenance aisées du scanner une fois le boîtier fermé, des déportations de connectiques ont été intégrées via des passes-cloisons :
\begin{itemize}
    \item \textbf{Liaison Réseau (RJ45) :} Un câble réseau part du Raspberry Pi vers une carte Ethernet, dont la sortie finale au format USB-C est fixée sur un passe-cloison. Le Raspberry Pi utilise l'adresse fixe \texttt{192.168.55.1} et exécute un serveur DHCP qui attribue automatiquement une adresse IP au PC connecté. L'interface du scanner est ainsi accessible directement par une liaison filaire, sans configuration réseau manuelle du PC.
    \item \textbf{Port de stockage (USB) :} Un second câble USB est relié du Raspberry Pi à un passe-cloison femelle, offrant un accès direct pour brancher une clé USB externe (exportation des scans).
\end{itemize}

\begin{figure}[H]
    \centering
    
    \caption{Schéma électrique — Page 2 : Câblage du Raspberry Pi, des capteurs, des caméras et commande des actionneurs via MOSFET.}
    \label{fig:sch_rpi}
\end{figure}

\subsection{Réalisation et intégration}
\label{subsec:integration}

    \subsubsection{Conception des circuits imprimés (PCB)}
    \label{subsubsec:pcb}

    Afin de concrétiser le schéma électrique et de fiabiliser les liaisons, la conception de la carte électronique a évolué en deux étapes distinctes.

    \paragraph{Version 1 : Prototype rapide}
    La première version du PCB a été réalisée manuellement dans le but d'obtenir un prototype fonctionnel le plus rapidement possible. Cette carte préliminaire intégrait uniquement les fonctions vitales du scanner : le module de régulation 5\,Vdc ainsi que l'étage de commande à transistors MOSFET (avec leurs résistances de polarisation) pour le laser et le moteur. 
    Bien que rudimentaire, cette version a permis de valider le code de test et de s'assurer du bon comportement dynamique des actionneurs.

    \begin{figure}[H]
    \centering
    
    \caption{Photo du prototype du PCB.}
    \label{fig:PCB_Photo_V1}
    \end{figure}

    \paragraph{Version 2 : Carte de centralisation finale}
    La seconde version a été entièrement conçue sur le logiciel de CAO KiCad, puis fabriquée à l'aide de la graveuse pour PCB disponible à la HEIG-VD. 
    L'objectif principal de ce nouveau PCB est la \textbf{centralisation absolue} des signaux et des puissances, agissant comme une carte d'interface (\textit{Shield}) pour le système.

    Cette architecture offre plusieurs avantages majeurs pour la maintenance et l'évolutivité de la machine :
    \begin{itemize}
        \item \textbf{Maintenance simplifiée :} Toutes les tensions et tous les signaux convergent sur cette carte. Si un élément doit être inspecté ou remplacé (comme le capteur de porte ou le laser), il suffit de le débrancher de son connecteur dédié sur le PCB sans avoir à manipuler les broches du Raspberry Pi. De même, le Raspberry Pi peut être isolé du système en débranchant seulement deux connecteurs (\texttt{J3} et \texttt{J5}).
        \item \textbf{Évolutivité (Ports de réserve) :} La carte intègre 5 connecteurs de réserve (\texttt{J6} à \texttt{J10}). Chaque bloc distribue les ressources nécessaires à la connexion d'un capteur ou d'un actionneur : une ligne 5\,Vdc, une ligne 3,3\,Vdc, une masse (GND) et une ligne GPIO dédiée.
        \item \textbf{Intégration et compacité (Technologie CMS) :} Afin d'optimiser l'espace, la carte utilise les deux faces du circuit. L'empreinte centrale traversante \texttt{U1} accueille directement le module convertisseur Buck LM2596 soudé sur la face avant (face composants). En contrepartie, les transistors MOSFET et leurs résistances de polarisation associés au laser et au moteur sont des composants montés en surface (CMS) brasés sur la face arrière (face pistes), évitant ainsi le perçage de trous superflus.
    \end{itemize}

    L'organisation des 12 connecteurs de la carte finale est répartie selon la nomenclature technique de la figure~\ref{fig:pcb_connecteurs} :
    \begin{itemize}
        \item \texttt{J1} : Entrée d'alimentation générale de la machine (24\,Vdc).
        \item \texttt{J2} : Sortie d'alimentation 24\,Vdc vers la puissance du driver \texttt{DM320T}.
        \item \texttt{J3} \& \texttt{J5} : Interface directe vers le Raspberry Pi (Distribution des alimentations et bus de signaux GPIO).
        \item \texttt{J4} : Signaux de pilotage adaptés (\texttt{PULL}, \texttt{DIR}, \texttt{ENA}) vers les optocoupleurs du driver.
        \item \texttt{J11} : Alimentation et commande du module Laser.
        \item \texttt{J12} : Connecteur pour le microswitch de sécurité du capot (Porte).
        \item \texttt{J6} à \texttt{J10} : Connecteurs d'extension (Réserve 1 à 5).
    \end{itemize}

    \begin{figure}[H]
        \centering
        \begin{subfigure}[b]{0.48\linewidth}
            \centering
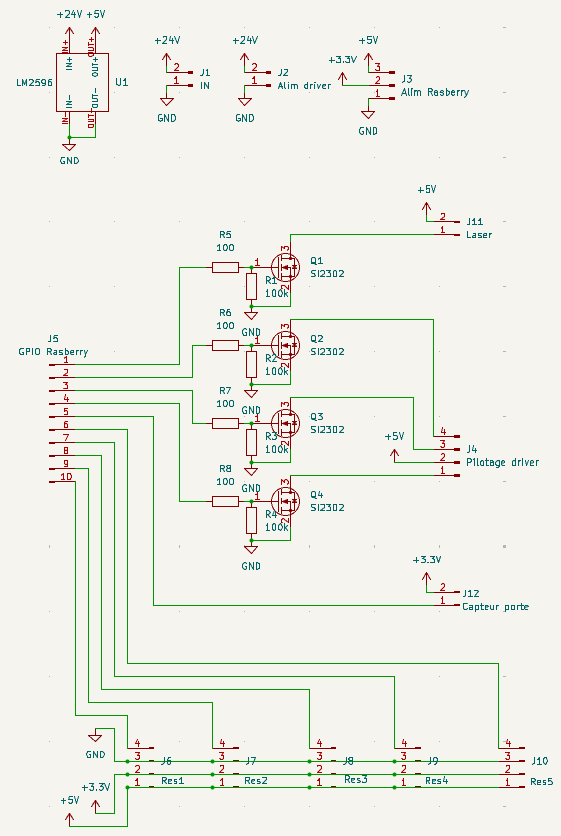
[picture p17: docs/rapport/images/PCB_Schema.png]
            
            \caption{Schéma électrique du PCB développé sous KiCad.}
            \label{fig:pcb_v2_schema}
        \end{subfigure}
        \hfill
        \begin{subfigure}[b]{0.48\linewidth}
            \centering
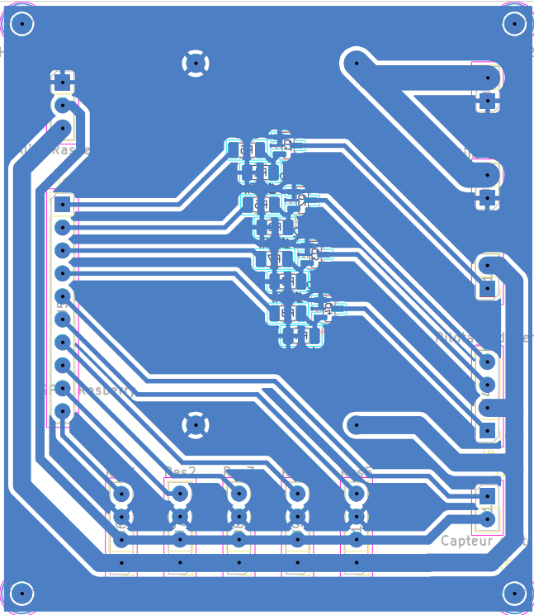
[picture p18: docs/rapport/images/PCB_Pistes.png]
            
            \caption{Dessin du routage des pistes (Face soudure).}
            \label{fig:pcb_v2_routage}
        \end{subfigure}
        
        \vspace{0.3cm}
        
        \begin{subfigure}[b]{0.48\linewidth}
            \centering
            
            \caption{Photo du résultat final du PCB fixé dans le scanner.}
            \label{fig:pcb_v2_photo}
        \end{subfigure}
        \hfill
        \begin{subfigure}[b]{0.48\linewidth}
            \centering
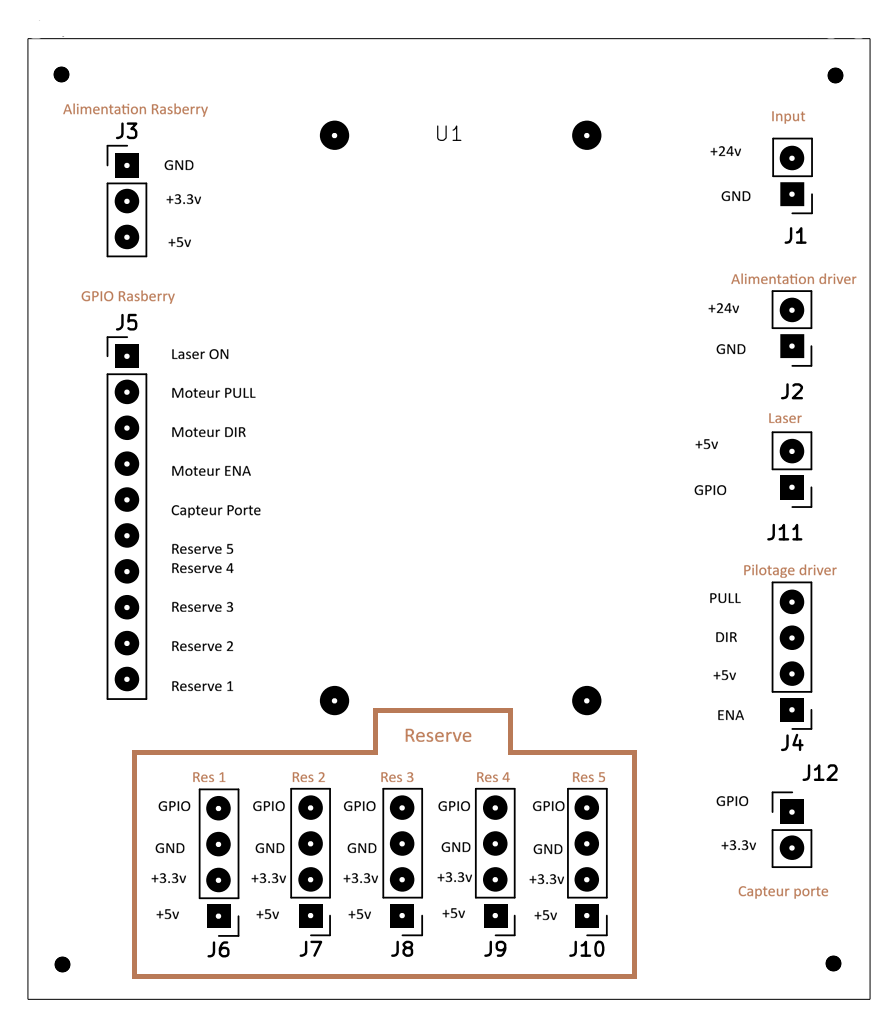
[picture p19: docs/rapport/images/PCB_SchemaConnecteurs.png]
            
            \caption{Plan d'implantation et fonction des connecteurs (Face composants).}
            \label{fig:pcb_connecteurs}
        \end{subfigure}
        \caption{Documentation technique et réalisation du PCB de centralisation final.}
        \label{fig:documentation_pcb_totale}
    \end{figure}

    \subsubsection{Câblage et implantation physique}
    \label{subsubsec:cablage}

    L'implantation physique des éléments et la gestion des conducteurs ont été étudiées pour garantir la fiabilité des signaux logiques et éviter tout incident mécanique lors des cycles de numérisation.

    \paragraph{Contraintes d'implantation}
    L'ensemble de l'électronique de commande (Raspberry Pi 4 et le PCB de centralisation) est fixé rigidement sur les parois internes du scanner 3D. 
    Cet emplacement est choisi pour maintenir le champ de vision des caméras totalement libre de tout obstacle visuel. 

    \paragraph{Gestion et guidage des câbles}
    Les nappes plates d'affichage (DSI) et de caméra (CSI) étant particulièrement fragiles et sensibles aux rayons de courbure trop faibles, un système de fixation dédié a été développé. Des goulottes de guidage ont été conçues sur mesure et réalisées en impression 3D (voir figure~\ref{fig:goulotte_3d}).

    Ces canaux sur mesure remplissent deux fonctions essentielles :
    \begin{itemize}
        \item \textbf{Sécurité mécanique :} Ils confinent les câbles d'alimentation et de signaux contre les parois, éliminant tout risque qu'un fil ne vienne s'enrouler autour de l'axe du moteur ou ne bloque le plateau rotatif en mouvement.
        \item \textbf{Esthétique et clarté :} Le rendu final (visible sur la vue d'ensemble de la figure~\ref{fig:photo_composants}) offre un espace de travail propre, indispensable pour faciliter les interventions de maintenance.
    \end{itemize}

    \begin{figure}[H]
        \centering
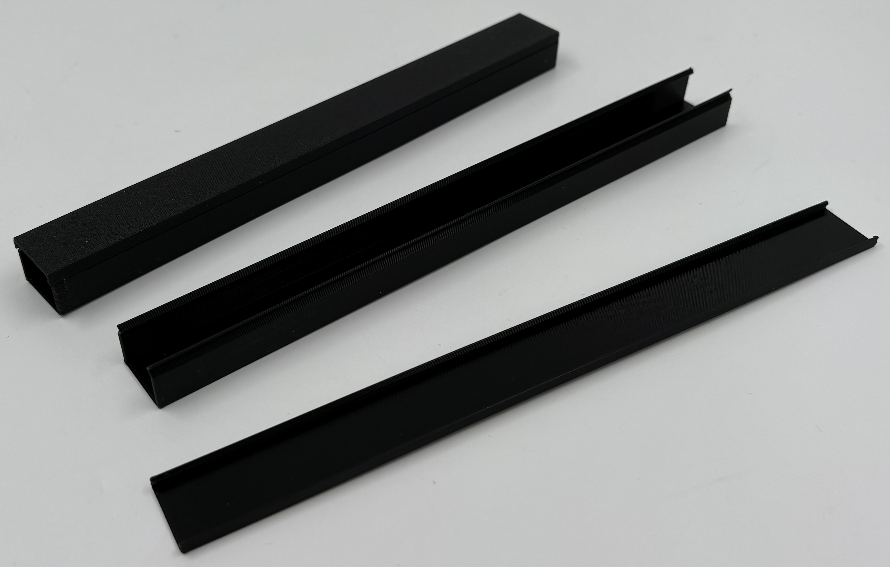
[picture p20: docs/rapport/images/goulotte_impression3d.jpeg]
        
        \caption{Guide-câble sur mesure réalisé en impression 3D pour le maintien des nappes et conducteurs.}
        \label{fig:goulotte_3d}
    \end{figure}

\subsection{Mesures électriques et consommation}
\label{subsec:mesures_electriques}

Des mesures de tension et de courant ont été effectuées sur le prototype afin
de vérifier le dimensionnement de l'alimentation et du convertisseur. Les
valeurs au repos et les valeurs maximales observées pendant un scan sont
regroupées dans le tableau~\ref{tab:mesures_electriques}.

\begin{table}[H]
    \centering
    \small
    \begin{tabular}{@{}p{5.1cm}c c c@{}}
        \toprule
        \textbf{Point mesuré} & \textbf{Tension} &
        \textbf{Courant au repos} & \textbf{Maximum en scan} \\
        \midrule
        Sortie du convertisseur logique & 5,5\,V & 1,55\,A & 1,80\,A \\
        Branche du moteur & 23,5\,V & 0,12\,A & 0,45\,A \\
        Alimentation principale & 23,5\,V & 0,55\,A & 0,91\,A \\
        \bottomrule
    \end{tabular}
    \caption{Tensions et courants mesurés sur le prototype.}
    \label{tab:mesures_electriques}
\end{table}

La sortie du convertisseur a été réglée à 5,5\,V afin de compenser les chutes
de tension dans les câbles d'alimentation. Avec un réglage initial à 5\,V, le
Raspberry Pi affichait un avertissement de sous-tension. L'augmentation à
5,5\,V en sortie du convertisseur a permis de supprimer cet avertissement
pendant le fonctionnement du scanner.

Le rendement du convertisseur est estimé à environ 82,8\,\%. À la consommation
maximale observée, l'alimentation principale délivre environ
$23{,}5\times0{,}91=21{,}4$\,W. Cette valeur reste inférieure à sa puissance
nominale de 24\,W, mais la marge disponible est limitée à environ 2,6\,W.

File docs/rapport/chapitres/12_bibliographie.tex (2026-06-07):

\section{Bibliographie}
\nocite{*}
\begingroup
\setlength{\emergencystretch}{2em}
\printbibliography[heading=none]
\endgroup

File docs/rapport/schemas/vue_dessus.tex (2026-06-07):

% Vue de dessus de la géométrie caméra / laser / plateau.
% Les azimuts proviennent de la calibration et des essais de regroupement.
\begin{tikzpicture}[scale=0.72, every node/.style={font=\scriptsize}]
  \draw[fill=softblue,draw=linegray] (0,0) rectangle (7.0,5.0);
  \node[deepblue,font=\small\bfseries] at (3.5,4.65) {vue de dessus};

  % Plateau rotatif.
  \draw[fill=white,draw=mutedgray,thick] (3.5,2.45) circle (1.25);
  \node[mutedgray,font=\tiny] at (3.5,1.00) {plateau};

  % Objet anguleux sur le plateau (vu de dessus).
  \begin{scope}[shift={(3.5,2.45)},rotate=28]
    \draw[fill=white,draw=deepblue,thick] (-0.42,-0.42) rectangle (0.42,0.42);
  \end{scope}

  \coordinate (O) at (3.5,2.45);
  \coordinate (cam1) at ($(O)+(155:2.05)$);
  \coordinate (cam2) at ($(O)+(213:2.05)$);

  % Source laser et plan laser passant par l'axe (côté gauche).
  \draw[fill=white,draw=lasergreen,thick] (0.30,2.27) rectangle (0.65,2.63);
  \draw[lasergreen,very thick] (0.65,2.45) -- (3.30,2.45);
  \draw[lasergreen,very thick,dashed,opacity=0.55] (3.30,2.45) -- (5.30,2.45);
  \node[lasergreen,font=\scriptsize\bfseries] at (1.05,2.12) {plan laser};

  % Caméra Pi (CSI), -25 deg par rapport au plan laser.
  \draw[deepblue,very thick,opacity=0.55] (O) -- (cam1);
  \fill[deepblue] (cam1) circle (0.14);
  \draw[deepblue,very thick] (cam1) circle (0.21);
  \node[deepblue,font=\scriptsize\bfseries,anchor=south east] at ($(cam1)+(-0.18,0.05)$) {Caméra Pi};
  \draw[deepblue,thick] ($(O)+(180:0.95)$) arc (180:155:0.95);
  \node[deepblue,font=\tiny] at ($(O)+(168:1.36)$) {$25^\circ$};

  % Caméra USB, +33 deg par rapport au plan laser.
  \draw[heigred,very thick,opacity=0.55] (O) -- (cam2);
  \fill[heigred] (cam2) circle (0.14);
  \draw[heigred,very thick] (cam2) circle (0.21);
  \node[heigred,font=\scriptsize\bfseries,anchor=north east] at ($(cam2)+(-0.18,-0.05)$) {Caméra Arducam};
  \draw[heigred,thick] ($(O)+(180:0.95)$) arc (180:213:0.95);
  \node[heigred,font=\tiny] at ($(O)+(201:1.42)$) {$33^\circ$};
\end{tikzpicture}

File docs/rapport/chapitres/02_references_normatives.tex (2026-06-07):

\section*{Références normatives}
\addcontentsline{toc}{section}{Références normatives}

Les documents suivants cites dans le texte constituent, pour tout ou partie de leur contenu,
des exigences du present document.

\begin{longtable}{@{}p{4.2cm}p{10cm}@{}}
\toprule
\textbf{Norme} & \textbf{Description} \\
\midrule
\endfirsthead
\toprule
\textbf{Norme} & \textbf{Description} \\
\midrule
\endhead
CDC-V2 & Cahier des charges fonctionnel - Version 2 (11.03.2026) \\
IEC 60825-1:2014 & Sécurité des appareils à laser : classification et exigences \\
ISO/IEC Dir 2:2016 & Principes et regles de structure et de redaction des documents ISO et IEC \\
OMG UML 2.5.1 & Unified Modeling Language pour l'ingenierie logicielle \\
\bottomrule
\end{longtable}

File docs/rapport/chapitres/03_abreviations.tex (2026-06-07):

\section*{Abréviations}
\addcontentsline{toc}{section}{Abréviations}

Cette section précise les terminologies techniques et acronymes propres
au projet.

\begin{longtable}{@{}p{2.7cm}p{12.7cm}@{}}
\toprule
\textbf{Terme} & \textbf{Définition} \\
\midrule
\endfirsthead
\toprule
\textbf{Terme} & \textbf{Définition} \\
\midrule
\endhead
CDC      & Cahier des charges \\
CSI      & Camera Serial Interface (bus caméra du Raspberry Pi) \\
FS / FT / FC & Fonctions de Service / Techniques / de Contrainte \\
GPIO     & General Purpose Input/Output \\
HEIG-VD  & Haute École d'Ingénierie et de Gestion du Canton de Vaud \\
KDTree   & K-Dimensional Tree (structure d'indexation spatiale) \\
MakeLab  & Laboratoire de prototypage et de fabrication de la HEIG-VD \\
NEMA     & National Electrical Manufacturers Association (norme moteurs) \\
PMD      & Projet multidisciplinaire \\
SSE      & Server-Sent Events \\
STL      & STereoLithography (format de maillage 3D) \\
USB      & Universal Serial Bus \\
MDF      & Medium Density Fiberboard (panneau de fibres de bois) \\
PLA      & Polylactic Acid (matériau d'impression 3D) \\
PCB      & Printed Circuit Board (circuit imprimé) \\
FSM      & Finite State Machine (machine d'états finis) \\
BOM      & Bill Of Materials (nomenclature) \\
RMS      & Root Mean Square (erreur quadratique moyenne) \\
ROI      & Region Of Interest (zone d'intérêt dans l'image) \\
\bottomrule
\end{longtable}

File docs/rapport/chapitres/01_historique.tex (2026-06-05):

\section*{Historique du document}
\addcontentsline{toc}{section}{Historique du document}

\begin{longtable}{@{}p{2.8cm}p{3.2cm}p{8.2cm}@{}}
\toprule
\textbf{Version} & \textbf{Date} & \textbf{Changements} \\
\midrule
\endfirsthead
\toprule
\textbf{Version} & \textbf{Date} & \textbf{Changements} \\
\midrule
\endhead
V0.1 & 15.02.2026 & Création du squelette de rapport \\
V0.5 & 11.03.2026 & Alignement sur le cahier des charges V2 \\
V1 & 27.04.2026 & Version intermédiaire (prototype mono-caméra) \\
\versionDocument & \dateDocument & Version finale : passage double caméra, fusion et reconstruction, budget et résultats finaux \\
\bottomrule
\end{longtable}

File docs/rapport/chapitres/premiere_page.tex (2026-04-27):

\thispagestyle{empty}

\begin{center}
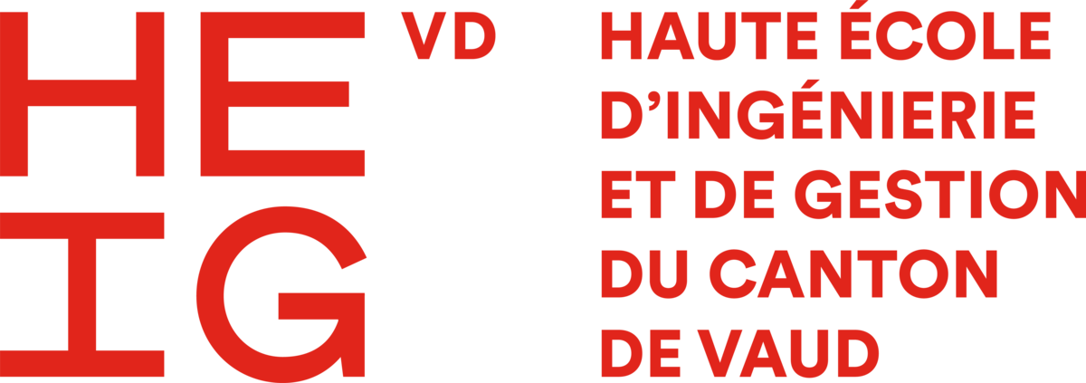
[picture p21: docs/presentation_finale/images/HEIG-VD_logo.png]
  
  \hfill
  
\end{center}

\vspace*{1.5cm}

\begin{center}
  {\Large \projetNom}\\[0.4cm]
  {\Large Rapport technique - \versionDocument}\\[0.3cm]
  {\large \filiere}
\end{center}

\vfill

\begin{center}
  \begin{tabular}{@{}lp{9.5cm}@{}}
    \textbf{Département :} & \departement \\
    \textbf{Unité d'enseignement :} & \uniteEnseignement \\
    \textbf{Rédigé par :} & \begin{tabular}[t]{@{}l@{}}\auteurs\end{tabular} \\
    \textbf{Professeur répondant :} & \professeurRepondant \\
    \textbf{Date:} & \dateDocument
  \end{tabular}
\end{center}

\vspace*{1.2cm}

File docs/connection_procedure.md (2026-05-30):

# Procedure de connexion et execution (Windows <-> Raspberry Pi)

## Objectif
Connecter un Raspberry Pi au PC Windows via cable Ethernet, garder Internet sur le Pi via le Wi-Fi du PC, puis acceder au scanner en SSH et HTTP.

## Resume rapide
- Utiliser **ICS (Internet Connection Sharing)** sur la carte Wi-Fi Windows.
- **Ne pas** utiliser le point d'acces mobile en meme temps.
- Le Pi et le PC doivent etre dans le **meme sous-reseau** Ethernet.
- La route par defaut du Pi doit pointer vers l'IP Ethernet du PC.

## 1. Branchement
1. Connecter le Raspberry Pi au PC avec un cable Ethernet.
2. Verifier que le Wi-Fi du PC est connecte a Internet.

## 2. Configuration Windows (ICS)
1. Ouvrir `Panneau de configuration > Reseau et Internet > Connexions reseau`.
2. Clic droit sur la carte **Wi-Fi** (celle qui a Internet) > `Proprietes`.
3. Onglet `Partage` :
4. Cocher `Autoriser d'autres utilisateurs du reseau a se connecter...`.
5. Selectionner la carte Ethernet branchee au Pi (ex: `Ethernet 4`).
6. Valider.
7. Verifier que le **Point d'acces mobile** Windows est **desactive**.

## 3. Verification des IP
### Cote Windows
Dans PowerShell:
```powershell
ipconfig
```
Repere l'interface Ethernet connectee au Pi (ex: `Ethernet 4`) et note son IPv4 (ex: `192.168.55.20`).

### Cote Raspberry Pi
En SSH ou terminal local:
```bash
ip a
ip route
```
Attendu:
- `eth0` a une IP du meme reseau (ex: `192.168.55.1/24`)
- route par defaut via l'IP Ethernet du PC (ex: `default via 192.168.55.20 dev eth0`)

## 4. Connexion au Raspberry Pi
Depuis Windows:
```powershell
ssh admin@192.168.55.1
```

## 5. Interface scanner
Dans le navigateur Windows:
```text
http://192.168.55.1:5000/
```

## 6. Mise a jour du code
Sur le Raspberry Pi:
```bash
cd ~/scanner3d-pmd
git pull
```

## 7. Checklist de debug
1. `ipconfig` Windows: l'Ethernet vers le Pi a une IPv4.
2. `ip a` Pi: `eth0` est `UP` et a une IPv4 du meme sous-reseau.
3. `ip route` Pi: `default via <IP_PC_ETHERNET>`.
4. `ping <IP_PC_ETHERNET>` depuis le Pi.
5. `ping 8.8.8.8` depuis le Pi.
6. Point d'acces mobile Windows desactive.

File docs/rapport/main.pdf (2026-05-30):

## Scanner 3D

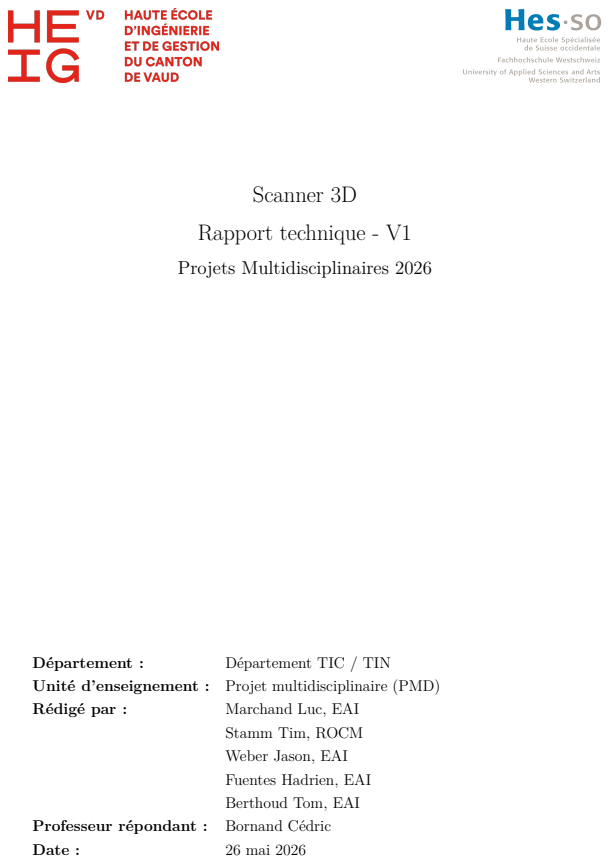
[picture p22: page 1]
Rapport technique - V1; Projets Multidisciplinaires 2026; Département :; Département TIC / TIN; Rédigé par :; Marchand Luc, EAI; Professeur répondant :; Bornand Cédric; Date :; 26 mai 2026

Unité d’enseignement : Projet multidisciplinaire (PMD)

Stamm Tim, ROCM
Weber Jason, EAI
Fuentes Hadrien, EAI
Berthoud Tom, EAI

Scanner 3D | Rapport technique - V1

## Historique du document

Version | Date | Changements
V0.1 | 15.02.2026 | Création du squelette de rapport
V0.5 | 11.03.2026 | Alignement sur le cahier des charges V2
V1 | 26 mai 2026 | Version intermédiaire

## Références normatives

Les documents suivants cites dans le texte constituent, pour tout ou partie de leur contenu, des exigences du present document.

Norme | Description
CDC-V2 | Cahier des charges fonctionnel - Version 2 (11.03.2026)
ISO/IEC Dir 2 :2016 | Principes et regles de structure et de redaction des do-
| cuments ISO et IEC
OMG UML 2.5.1 | Unified Modeling Language pour l’ingenierie logicielle

## Abréviations

Cette section précise les terminologies techniques et acronymes propres au projet.

Terme | Définition
CDC | Cahier des charges
CSI | Camera Serial Interface (bus caméra du Raspberry Pi)
FS / FT / FC | Fonctions de Service / Techniques / de Contrainte
GPIO | General Purpose Input/Output
HEIG-VD | Haute École d’Ingénierie et de Gestion du Canton de Vaud
KDTree | K-Dimensional Tree (structure d’indexation spatiale)
MakeLab | Laboratoire de prototypage et de fabrication de la HEIG-VD
NEMA | National Electrical Manufacturers Association (norme moteurs)
OBJ | Format de fichier de modèle 3D (Wavefront)
PMD | Projet multidisciplinaire
SSE | Server-Sent Events
STL | STereoLithography (format de maillage 3D)
USB | Universal Serial Bus
26 mai 2026 | ii/31

Terme | Définition
MDF | Medium Density Fiberboard (panneau de fibres de bois)
PLA | Polylactic Acid (matériau d’impression 3D)
26 mai 2026 | iii/31

## Table des matières

Historique du document | ii
Références normatives | ii
Abréviations | ii
1 Introduction | 1
2 Conception mécanique | 3
3 Conception électronique | 8
4 Software | 13
26 mai 2026 | iv/31

5 Système électrique | 19
6 Régulation | 21
7 Prototype | 23
8 Conclusion | 27
26 mai 2026 | v/31

9 Bibliographie | 29
10 Annexes | 30
26 mai 2026 | vi/31

## Table des figures

1 | Prototype mécanique au rapport intermédiaire : boîte MDF découpée laser,
2 | Électronique du prototype au rapport intermédiaire : Raspberry Pi 4, écran tactile, driver DM320T, étage de commande sur carte perforée et supports
4 | Schéma électrique — étage Raspberry Pi, pilotage actionneurs et capteurs. | 11
6 | Chaîne de traitement observée sur le prototype réel : de la capture image
10 | Limite de visibilité en configuration mono-caméra : sur une pièce anguleuse, le laser éclaire une zone de la pièce mais celle-ci peut être masquée à la
26 mai 2026 | vii/31

## Liste des tableaux

4 | Objectifs SMART du projet, alignés sur les exigences du cahier des charges. | 2
5 | Phases du projet | | 2
6 | Répartition du travail | | 3
7 | Composants électroniques principaux et interfaces | | 8
8 | Modules logiciels et responsabilités | 15
9 | Bibliothèques et justifications | 18
10 | Rails d’alimentation et répartition des charges | 20
11 | Bilan de consommation intermédiaire | 20
12 | Sources d’erreur observées ou probables et actions prévues | 23
13 | État de maturité des sous-systèmes au rapport intermédiaire | 24
14 | Performances intermédiaires et mesures restantes | 26
15 | Revue des objectifs au rapport intermédiaire | 28
26 mai 2026 | viii/31

## 1 Introduction

### 1.1 Contexte

Ce projet s’inscrit dans le cadre de l’unité d’enseignement Projets Multidisciplinaires 2026, HEIG-VD. Il consiste à concevoir et réaliser un scanner 3D destiné au MakeLab de l’école, afin de mettre à disposition des étudiants, collaborateurs et enseignants un outil simple pour numériser des objets physiques en modèles 3D exploitables (STL ou OBJ).

### 1.2 État de l’art

Les solutions de numérisation 3D du marché se répartissent en trois familles : les scanners professionnels à structure de lumière (EinScan, Revopoint) offrant une précision élevée

mais dont le prix dépasse largement le budget d’un projet étudiant, les scanners grand public (par exemple Creality CR-Scan ou Matter and Form) plus abordables mais souvent

liés à un écosystème logiciel constructeur, et les projets open-source à triangulation laser ou photogrammétrie.

La valeur ajoutée de l’approche retenue tient à trois points : un coût contenu sous 300 CHF, une intégration pensée pour un usage pédagogique (interface web, retour LED et écran, prise en main rapide) et une architecture ouverte permettant d’expliquer, modifier et

améliorer chaque étape de la chaîne de mesure.

### 1.3 But et objectifs

Problématique. Comment concevoir et intégrer, dans un budget de 300 CHF, un scanner 3D suffisamment simple pour être utilisé en autonomie au MakeLab, tout en garantissant la sécurité de l’utilisateur et une qualité de mesure exploitable ?

Objectifs SMART. Les objectifs mesurables dérivés du cahier des charges [1] sont les

suivants :

26 mai 2026 | 1/31

Réf. | Objectif
O1 | Numériser de manière automatisée un objet de dimension maximale 150 × 150 × 150 mm (E1, E3).
O2 | Produire un fichier exportable au format STL ou OBJ (E6).
O3 | Réaliser un cycle de scan complet en moins de 10 minutes (besoin
| utilisateur B4 du CDC).
O4 | Garantir une prise en main inférieure à 10 minutes et un scan sans assistance dans au moins 90 % des cas sur 10 essais (E7).
O5 | Respecter un budget total inférieur ou égal à 300 CHF (E16).
O6 | Assurer la protection de l’utilisateur : matériaux non toxiques, arêtes non tranchantes, isolation du rayon laser et des zones mobiles (E17,
| E18, E19).
O7 | Fournir un retour visuel de l’état du système (LEDs et écran) (E5).
O8 | Offrir une interface de commande USB et/ou web permettant de lancer
| un scan en au plus 5 actions (E10, E11).
O9 | Atteindre une erreur absolue moyenne ≤ 2 mm et une répétabilité
| (écart-type) ≤ 1 mm sur 3 scans successifs du même objet de référence
| (E24).
O10 | Respecter un encombrement ≤ 500×500×500 mm et une masse totale
| ≤ 15 kg (E21).
O11 | Se limiter aux objets sans cavité fermée et sans contre-dépouille supé- rieure à 45◦ (E23).

Table 4 – Objectifs SMART du projet, alignés sur les exigences du cahier des charges.

### 1.4 Planification

Le projet est structuré en quatre phases principales, réparties sur 16 semaines pour un effort total estimé à 322 heures (hors imprévus et gestion de projet). La livraison du prototype fonctionnel est fixée au 7 juin 2026 (E22).

Phase Contenu | Fenêtre
T10 | Élaboration et vérification du concept (re-
cherche, CDC, sélection des composants)

Semaines 1–8

T20 Prototype pour la démonstration de concept (mécanique, électronique, logiciel)

Semaines 5–10

T30 Mise au point et intégration finale (UI, intégration, tests système)

Semaines 9–14

T40 Préparation des livrables (rapport, vidéo, démonstration)

Semaines 13–16

Table 5 – Phases du projet.

Répartition du travail. L’équipe est composée de cinq membres. La table 6 synthétise les responsabilités principales ; le détail tâche par tâche figure dans le planning en

annexe (10.1).

Membre | Responsabilité principale
Tom Berthoud (EAI) | Architecture logicielle, triangulation, coordination.
Jason Weber (EAI) | Interface utilisateur, reconstruction, export.
Luc Marchand (EAI) | Électronique, schéma, alimentation et sécurité.
Hadrien Fuentes (EAI) | Câblage, acquisition, mise en place et test.
Tim Stamm (ROCM) | Conception mécanique, boîtier, plateau rotatif.

Table 6 – Répartition du travail.

Livrables. Rapport technique (ce document), prototype fonctionnel au MakeLab, vidéo

de démonstration, présentation finale et jeu de scans d’objets de référence.

### 1.5 État intermédiaire du projet

Au 27 avril, un prototype physique existe : boîte découpée au laser, plateau motorisé, laser monté sur support imprimé en 3D, caméra placée à environ 30◦
, électronique d’alimentation et de commande, LEDs, écran et interface web. Un cycle de scan réel peut être lancé et produit un résultat exploitable pour l’analyse.

Les essais montrent cependant que la qualité finale du modèle dépend encore fortement de trois points : la visibilité de la ligne laser par la caméra, la robustesse de l’extraction de points et la reconstruction du maillage STL à partir du nuage de points. Le présent rapport intermédiaire documente donc à la fois les éléments validés, les limites identifiées et les actions prévues pour la phase suivante.

## 2 Conception mécanique

### 2.1 Architecture mécanique

Le scanner se présente sous la forme d’une boîte fermée de dimensions extérieures inférieures à 500 × 500 × 500 mm pour une masse totale inférieure à 15 kg (exigence E21).

L’architecture est pensée pour une intégration directe dans l’environnement du MakeLab de la HEIG-VD (FC3) et pour limiter l’accès utilisateur aux pièces mobiles ainsi qu’au

faisceau laser.

Au rapport intermédiaire, un premier prototype physique est fabriqué. Il comprend une boîte découpée au laser et refermable, un plateau rotatif découpé au laser, un moteur pas-à-pas, un support de laser imprimé en 3D et un support de caméra imprimé en 3D.

La caméra principale est montée avec une inclinaison d’environ 30◦ , cohérente avec la
géométrie de triangulation prévue (FT4 / E12).

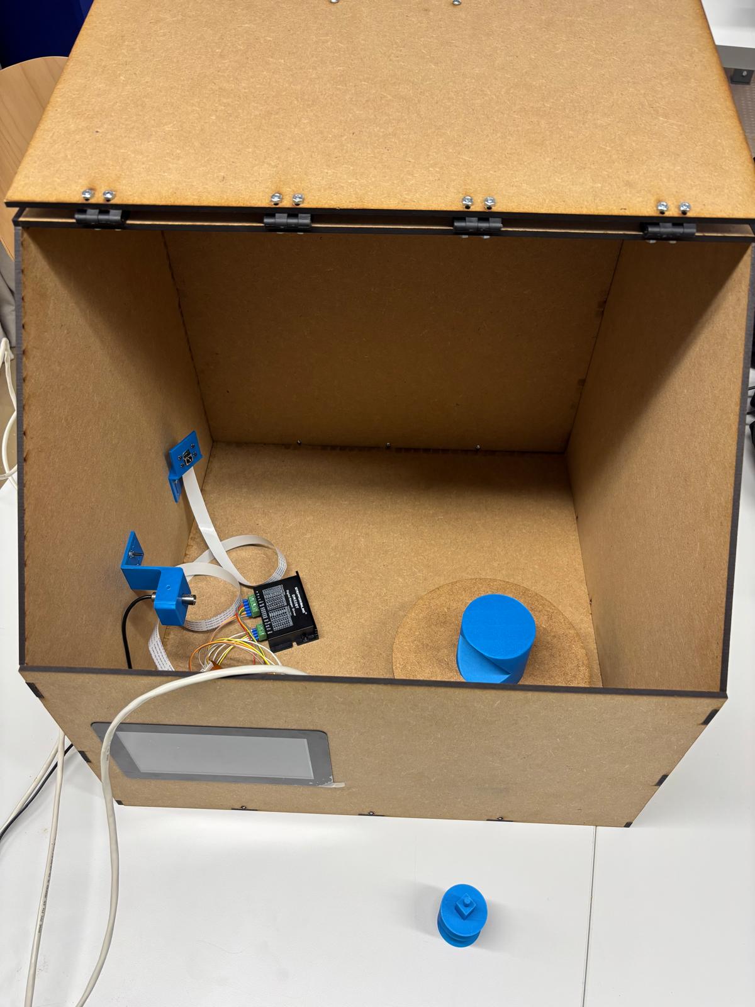
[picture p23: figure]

(a) Vue extérieure, capot ouvert.

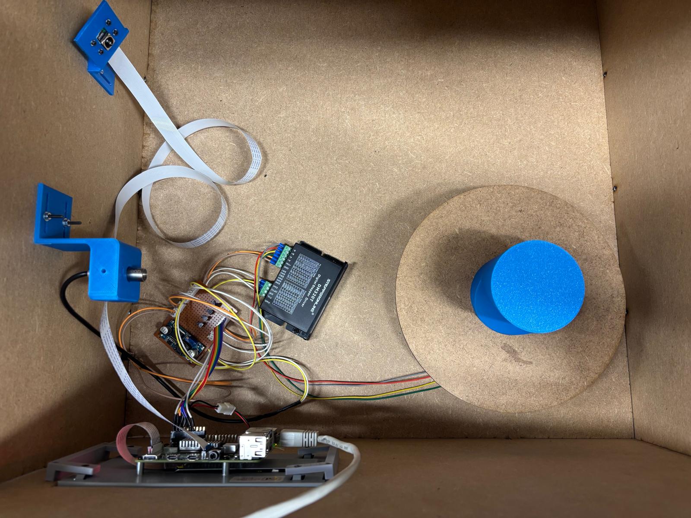
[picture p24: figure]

(b) Vue intérieure de dessus.

Figure 1 – Prototype mécanique au rapport intermédiaire : boîte MDF découpée laser, plateau rotatif, supports caméra et laser imprimés en 3D.

Le système s’organise autour de trois sous-ensembles :

— Plateau rotatif motorisé (FT7, E15) : support de l’objet à numériser, entraîné par un moteur pas-à-pas NEMA 17. Le plateau est centré dans l’enceinte et son axe de rotation est aligné avec le plan de mesure défini par le laser et la caméra. Le plateau fonctionne pour les essais, mais l’adhérence et le centrage des objets doivent encore être améliorés.
— Bâti de mesure : supporte la caméra Pi Camera 3 et le module laser ligne vert dans une géométrie fixe. La caméra est positionnée dans le coin supérieur opposé au plateau rotatif, tandis que le laser est fixé sur la façade opposée au plateau, garantissant une projection centrée sur la zone de numérisation. Les supports imprimés en 3D constituent une solution adaptée au projet : ils permettent de positionner rapidement les éléments optiques, d’itérer sur les angles et de rester compatibles avec les moyens de fabrication du MakeLab. Leur géométrie devra toutefois être affinée pour améliorer la précision de positionnement, la stabilité et la durabilité. — Plaques en bois : boîte fermable assurant le confinement mécanique et lumineux. Des ouvertures résiduelles doivent encore être isolées afin d’empêcher toute fuite du rayon laser hors de la boîte.

### 2.2 Zone de scan et périmètre fonctionnel

La zone utile est dimensionnée pour accueillir un objet maximal de 150 × 150 × 150 mm (E3). La boîte a été dimensionnée à 500 × 500 × 500 mm, résultant d’un compromis entre

l’espace nécessaire pour accueillir la pièce, les distances optiques requises pour la triangulation, le placement des composants électroniques et la contrainte de taille raisonnable pour le MakeLab (E21).

Conformément au périmètre fonctionnel E23, le système cible les pièces simples :

— sans cavité fermée ou profonde non accessible par les lignes de vue caméra/laser ; — sans contre-dépouille supérieure à 45◦ par rapport à l’axe de rotation ;

— avec une surface suffisamment visible par la caméra et la ligne laser.

Les essais sur pièce rectangulaire montrent une limite importante de la configuration mono-caméra : lorsque le laser passe sur un angle, la surface éclairée peut être masquée par une face de l’objet. Dans ce cas, la caméra ne voit plus la ligne laser, même si le laser atteint bien la pièce. Cette limite est physique et ne peut pas être corrigée uniquement par logiciel.

### 2.3 Choix des matériaux et fabrication

Le prototype intermédiaire utilise principalement deux types de matériaux et procédés de fabrication :

Boîte et plateau rotatif (MDF) La boîte et le plateau rotatif sont réalisés en MDF (Medium Density Fiberboard). Ce matériau a été retenu pour sa facilité d’usinage à la

découpe laser et sa rigidité suffisante. Le MDF présente également une bonne opacité, contribuant à l’isolation lumineuse de la zone de scan (FT1 / E9), et permet de minimiser

les reflets et diffusions parasites du faisceau laser lors du scan.

Supports caméra, laser, moteur et plateau rotatif (PLA imprimé en 3D) Ces supports sont fabriqués par impression 3D en PLA. L’impression 3D n’est pas un choix provisoire par défaut : elle est pertinente pour ce projet, car elle permet une itération rapide au MakeLab, un coût faible et une adaptation précise aux composants retenus. Le PLA est inerte, non toxique (E17), léger et suffisamment rigide pour ce stade de

prototypage. Les supports actuels seront donc améliorés, notamment sur leur géométrie et leur rigidité locale, plutôt que remplacés par une solution plus lourde.

Pour la version suivante, trois améliorations mécaniques sont retenues :

— ajouter une surface adhérente sur le plateau pour éviter le glissement des objets pendant la rotation ;
— ajouter un marquage de centrage afin de faciliter le placement de la pièce par l’utilisateur ;
— prévoir le déplacement ou l’adaptation des supports lors de l’ajout probable d’une deuxième caméra.

Les pièces étalons imprimées en 3D disposent déjà de deux petites tiges qui s’insèrent dans deux trous du plateau. Cette solution est utile pour les tests répétables, mais elle ne suffit pas pour des objets quelconques posés librement par un utilisateur.

### 2.4 Dimensionnement et stabilité

Les panneaux de la boîte sont assemblés par un système d’encoches et de rainures par emboîtement, vu lors du cours ProFabMT 2026, garantissant la rigidité de la structure et facilitant le montage et le démontage. Le support du plateau rotatif assure la liaison entre le moteur et le plateau via des inserts filetés, garantissant une fixation robuste et démontable. La fixation au moteur est assurée par une vis sans tête et un écrou. Les autres supports sont assemblés avec vis et écrou.

Le dimensionnement du plateau rotatif vise un couple suffisant pour supporter un objet de masse modérée à vitesse lente. Le moteur NEMA 17 sélectionné reste adapté aux essais actuels : aucun blocage majeur du moteur ou du plateau n’a été observé pendant les scans réalisés. Le point à améliorer n’est donc pas le couple moteur, mais la stabilité de la pièce sur le plateau et la précision de son centrage.

La rigidité des supports caméra et laser est également critique. Une variation de position ou d’angle modifie directement la calibration et peut provoquer une erreur de triangulation. Les supports imprimés en 3D seront donc conservés comme principe de fabrication, mais leur forme sera améliorée pour obtenir un montage plus stable, réglable si nécessaire et verrouillable après calibration.

### 2.5 Sécurité mécanique

Deux mesures principales assurent la protection de l’utilisateur :

— Confinement des pièces mobiles (E18) : le plateau et le moteur sont placés

dans une boîte fermée, limitant l’accès direct pendant un scan.
— Confinement du laser (E19) : la boîte refermable limite l’exposition directe au

faisceau. Les petits trous et ouvertures encore présents devront être obturés avant une utilisation utilisateur.

L’interlock de capot prévu dans le cahier des charges n’est pas encore monté sur le prototype de test. Les essais actuels sont donc réalisés dans un cadre contrôlé, avec activation volontaire du laser et présence de l’équipe.

### 2.6 Limites identifiées et actions prévues

— Occultations caméra : l’ajout d’une deuxième caméra, probablement USB, est la piste principale pour réduire les zones non visibles.
— Glissement des objets : une surface adhérente et un marquage de centrage doivent être ajoutés au plateau. Un système de fixation rapide pourrait également être intégré pour maintenir la pièce en place durant la rotation.
— Stabilité des supports : les supports caméra/laser imprimés en 3D doivent être

améliorés en géométrie, en rigidité et éventuellement en réglage.Le maintien du laser devrait également être revu avec un système de serrage ou de bridage dédié. — Sécurité laser : les ouvertures résiduelles de la boîte doivent être isolées et l’interlock de capot intégré.
— Améliorations de la boîte : des découpes dédiées pourraient être intégrées pour le montage des ports de connectique (USB, alimentation). L’ajout d’un vérin per-

mettrait de maintenir la porte ouverte sans intervention de l’utilisateur, et l’intégration d’un aimant garantirait une fermeture hermétique lors de l’acquisition.
— Plateau rotatif : le plateau pourrait être agrandi pour accueillir des pièces de dimensions supérieures, et l’interface avec le moteur repensée avec un accouplement rigide, garantissant un meilleur alignement axial et une transmission du couple plus fiable.

## 3 Conception électronique

### 3.1 Vue d’ensemble

L’électronique du scanner repose sur une carte Raspberry Pi 4 qui pilote les actionneurs et capteurs via ses GPIO. Les fonctions techniques adressées sont la capture des images (FT4), le pilotage du plateau rotatif (FT7), la commande du laser et la communication avec l’utilisateur (FT2, FT3).

Au rapport intermédiaire, l’architecture électronique est définie et les fonctions principales sont opérationnelles en test : alimentation du système, commande du laser, rotation du moteur, acquisition caméra, retour par LEDs et écran. L’intégration de sécurité du capot reste à finaliser.

Fonction | Composant | Interface
Unité de calcul | Raspberry Pi 4 Model B 4 GB | —
Acquisition image | Pi Camera Module 3 (IMX708) | CSI
Éclairage structuré | Laser ligne vert VLM-
| 520 | GPIO via étage de commande
Rotation plateau | Moteur NEMA 17 + driver DM320T | GPIO via étage de commande & les signaux Ena, Dir, Pull
Interface locale | Écran tactile 7 pouces port DSI
Sécurité porte | Fin de course / inter- lock à intégrer | GPIO entrée

Table 7 – Composants électroniques principaux et interfaces.


Figure 2 – Électronique du prototype au rapport intermédiaire : Raspberry Pi 4, écran tactile, driver DM320T, étage de commande sur carte perforée et supports laser/caméra.

### 3.2 Alimentation électrique

L’alimentation du système est assurée par un module externe convertissant le secteur 230 V AC en une tension continue de 12 V. Cette tension constitue la source d’énergie pour l’ensemble de la machine.

Un interrupteur principal est placé en sortie de l’alimentation afin de permettre la mise sous et hors tension du système en toute sécurité.

À partir de cette tension 12 V, un convertisseur abaisseur (buck converter) est utilisé pour

générer une tension régulée de 5 V. Cette tension est notamment utilisée pour alimenter les éléments nécessitant un niveau de tension plus faible, comme certaines interfaces logiques ou modules électroniques.

Cette architecture permet d’assurer une alimentation adaptée à chaque composant tout en garantissant une bonne efficacité énergétique et une séparation claire entre les étages de puissance et de commande.

GRAUND 1 N; 230Vac - 12Vdc; 12VDC; GND; +OUT HW-411; IN 4-40V, OUT 1.3 -35V, 2A; 5VDC 5VDC; Interrupteur principal

Transformateur externe à la machine

IN GND OUT GND

Schematic | Schéma électrique Scan3D | Create at | 2026-03-18

Update at | 2026-03-19

Board | | Page | Alimentation
Drawn | | Schema_Scan3D
Reviewed

Version | Size | Page 1 Total 2
V1.0 | A4 | EasyEDA.com

Figure 3 – Schéma électrique — étage alimentation électrique.

3.3 Schéma Raspberry Pi

La figure 4 du schéma électronique présente le câblage autour du Raspberry Pi : pilotage
du laser et du moteur au travers d’un étage de commande, détection de l’ouverture du
capot, connexion de l’écran et de la caméra.

Schematic; Schéma électrique Scan3D; Create at; Update at; Board; Page; Raspberry PI; Drawn; Schema_Scan3D; Reviewed; Version; Size; Page 2 Total 2; EasyEDA.com; GPIO15/RXD 10; GPIO17 11 GPIO18/PWM0 12; GPIO27 13; GND 14; GPIO22 15 GPIO23 16; GPIO24 18; MOSI0/GPIO10 19 ⁵V; GND 20; MISO0/GPIO9 21; GPIO25 22; SCLK0/GPIO11 23; {CE0}/GPIO8 24; GND 25; {CE1}/GPIO7 26; ID_SD/GPIO0 27 ID_SC/GPIO1 28; GCLK1/GPIO5 29; SDA/GPIO2 3; GND 30; GCLK2/GPIO6 31; PWM0/GPIO12 32 PWM1/GPIO13 33 GND 34; GPIO19/MISO1 35; GPIO16 36; GPIO26 37; GPIO20/MOSI1 38; GND 39; GPIO21/SCLK1 40; SCL/GPIO3 5; GND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

Figure 4 – Schéma électrique — étage Raspberry Pi, pilotage actionneurs et capteurs.

### 3.3.1 Etage de commande des GPIO

Le Raspberry Pi ne peut pas piloter directement les actionneurs (laser et moteur) en raison

de leurs exigences en tension et en courant. Un étage de commande est donc nécessaire pour faire l’interface entre les signaux logiques du Raspberry Pi et les composants à piloter.

En effet, le laser ainsi que le moteur nécessitent une alimentation en 5 V, tandis que les GPIO du Raspberry Pi fonctionnent en 3,3 V et ne peuvent fournir que quelques milliampères. Cela est insuffisant pour alimenter directement ces dispositifs, et pourrait même endommager le Raspberry Pi.

Pour résoudre ce problème, nous utilisons un étage de commande à base de transistors MOSFET. Le principe de fonctionnement est le suivant : la sortie GPIO du Raspberry Pi est reliée à la grille du MOSFET. Lorsque le GPIO est à l’état haut (3,3 V), une tension

est appliquée entre la grille et la source, ce qui rend le MOSFET passant. Le transistor se comporte alors comme un interrupteur fermé.

Dans cet état, le courant peut circuler entre le drain et la source du MOSFET. La charge (laser ou entrée de commande du contrôleur moteur), alimentée en 5 V, est alors reliée à la masse à travers le MOSFET. On parle de commande en low-side switching (commutation

côté masse).

Lorsque le GPIO est à l’état bas (0 V), la tension grille-source devient nulle, le MOSFET se

bloque et agit comme un interrupteur ouvert. Le courant ne circule plus, ce qui désactive la charge.

Ce montage permet ainsi de piloter des charges en 5 V à partir d’un signal logique 3,3 V, tout en protégeant le Raspberry Pi et en fournissant le courant nécessaire aux actionneurs. Des résistances sont également ajoutées pour assurer un fonctionnement stable, notamment pour éviter les états flottants et limiter les courants parasites.

### 3.3.2 Pilotage du laser et signaux logiques

Le laser est commandé électroniquement et peut être allumé ou éteint volontairement pendant les essais. Le logiciel impose l’extinction du laser en cas d’erreur de scan et le laser reste désactivé par défaut au démarrage, conformément aux règles de sécurité du projet.

La validation intermédiaire montre que la commande fonctionne, mais la sécurité finale ne peut pas se limiter au logiciel. L’interlock de capot doit encore être intégré afin que l’ouverture de la boîte coupe ou interdise l’activation du laser.

### 3.3.3 Pilotage du moteur

Le driver DM320T reçoit les signaux Ena, Dir et Pull du Raspberry Pi. Le moteur entraîne le plateau pendant les scans réels et ne constitue pas, à ce stade, le blocage principal. Les améliorations attendues concernent plutôt le maintien mécanique de la pièce et le centrage sur le plateau.

### 3.3.4 Affichage

L’écran est fonctionnel et permet d’afficher l’état du système. Ce dernier sert d’interface locale pour l’utilisation sans ordinateur externe. L’interface web et répond à l’exigence de retour utilisateur (E5). La version finale devra afficher sur l’écran tous les états de la

machine d’états logicielle : attente, scan, traitement, fin et erreur.

### 3.3.5 Capteur de porte

Le capteur de porte prévu n’est pas encore intégré au prototype utilisé pour les essais. Il reste donc à câbler et valider le comportement suivant : ouverture du capot pendant ou avant un scan, désactivation immédiate du laser et passage dans un état sûr.

### 3.4 Justification des choix

— Raspberry Pi 4 : capacité CPU suffisante pour le traitement Python, interface réseau intégrée et compatibilité avec la caméra Pi.
— Pi Camera Module 3 : bonne sensibilité au 520 nm sur le canal vert, ce qui facilite l’extraction de la ligne laser.
— Driver DM320T : adapté au moteur NEMA 17, il offre la précision de pilotage souhaitée. De plus, c’était le seul modèle disponible dans le stock du MakeLab conforme aux caractéristiques nécessaires.
— Pi Touch Display 2 : retour utilisateur local même sans ordinateur connecté à l’interface web.

### 3.5 Limites identifiées et actions prévues

— Intégrer le capteur de capot et vérifier la coupure du laser.
— Finaliser le câblage pour une utilisation durable et propre dans la boîte.
— Vérifier que toutes les ouvertures mécaniques ne permettent pas la sortie du faisceau laser.
— Prévoir l’intégration électrique d’une deuxième caméra USB si les essais de réduction des occultations confirment cette piste.

## 4 Software

### 4.1 Principe général

Le logiciel pilote le scanner et transforme une série d’images du plan laser déformé par l’objet en un modèle 3D exportable (STL ou OBJ), conformément aux exigences E6 et E13. Le traitement suit un pipeline linéaire : Acquisition → Extraction → Triangulation → Reconstruction → Export.

Au rapport intermédiaire, ce pipeline n’est plus seulement validé en simulation. Il est utilisé sur le prototype réel : un scan peut être lancé depuis l’interface web, les images sont capturées, la ligne laser est extraite, un nuage de points est produit et un fichier STL peut être exporté. Les limites actuelles se situent principalement dans l’extraction incomplète de certains points et dans la reconstruction du maillage à partir du nuage.

### 4.2 Architecture logicielle

L’architecture est modulaire : chaque responsabilité est isolée dans un sous-paquet Python exposant une API stable. Cette séparation a permis de développer d’abord en mode mock, puis de transférer le pipeline sur le matériel réel sans réécrire l’ensemble du système.


Figure 5 – Architecture logicielle — vue des composants et flux de données.

Module | Responsabilité
hardware | Abstraction du moteur, laser, LEDs, écran et caméra, avec
| mode mock.
acquisition | Séquence moteur, laser, capture image et sauvegarde des
| images.
processing | Extraction de la ligne laser et triangulation pixel → point
| 3D.
reconstruction | Fusion des profils en nuage de points et filtrage.
export | Génération STL / OBJ et export du nuage brut.
orchestration | Machine d’états et workflow de scan.
calibration | Outils de calibration caméra, laser et filtres de fond.
interface | Serveur web Flask, SSE, viewer 3D, commandes manuelles
| et écran local.

Table 8 – Modules logiciels et responsabilités.

### 4.3 Chaîne de traitement réelle

La chaîne réelle actuellement observée est la suivante :

1. capture d’une image nette avec une ligne laser visible ;
2. extraction des points de la ligne laser ;
3. conversion des points image en nuage de points 3D ;
4. export d’un STL à partir du nuage.


(1) Capture | (2) Extraction


(3) Nuage de points | (4) STL exporté

Figure 6 – Chaîne de traitement observée sur le prototype réel : de la capture image jusqu’au fichier STL.

L’acquisition image est jugée de bonne qualité. L’extraction récupère une grande partie de la ligne laser, de l’ordre de 90 % sur les essais actuels, mais perd encore des points.

Deux cas sont distingués : soit le laser est physiquement invisible pour la caméra à cause d’une occultation, soit le laser est visible mais l’algorithme ne détecte pas tous les points à cause des paramètres de seuil ou de la méthode d’extraction.

La transformation des points extraits en nuage de points donne un rendu propre et exploitable pour l’analyse. Le passage du nuage de points au STL reste le point logiciel le plus critique, surtout pour les formes non cylindriques ou anguleuses.

### 4.4 Orchestration et machine d’états

La machine d’états centralise les transitions légales et déclenche les effets de bord associés : changement de LED, progression de l’interface, arrêt du laser en cas d’erreur. Les états

IDLE, CALIBRATING, SCANNING, PROCESSING, EXPORTING, COMPLETE et ERROR couvrent l’ensemble du cycle de vie.


Figure 7 – Machine d’états du scanner — transitions et signalisation LED.

Sécurité laser. Le logiciel désactive le laser au démarrage et lors d’un passage en état ERROR. Ce comportement est nécessaire mais ne remplace pas l’interlock matériel du capot, qui reste à intégrer pour la version utilisateur.

### 4.5 Calibration

Le pipeline s’appuie sur trois familles de paramètres : intrinsèques caméra, plan laser et géométrie de la plateforme. Les essais actuels ont permis d’obtenir une calibration suffisante pour retrouver des dimensions cohérentes en largeur et en profondeur sur des objets simples. La hauteur du modèle reste toutefois déformée vers le haut ; la cause n’a pas encore été isolée et devra être diagnostiquée lors de la prochaine phase.

La caméra présente encore de la distorsion. Le protocole final devra stabiliser la calibration caméra, la calibration du plan laser et la position de l’axe de rotation, puis vérifier leur cohérence sur des pièces étalons.
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

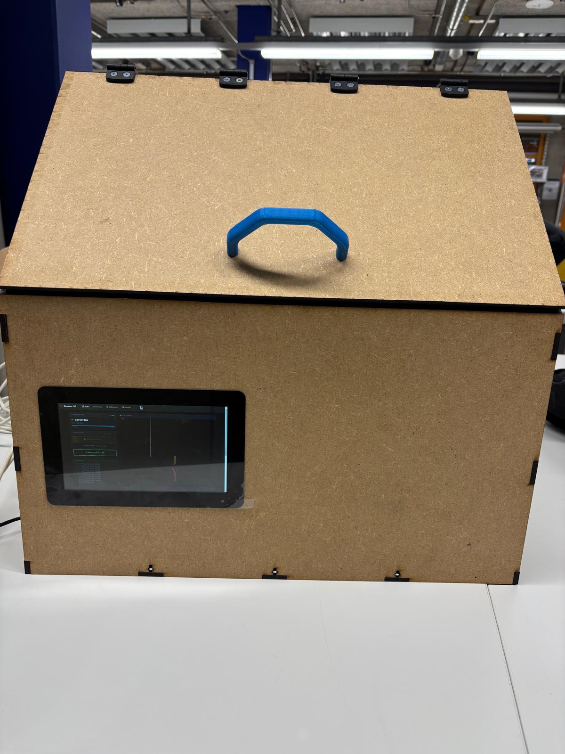
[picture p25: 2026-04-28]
docs/rapport/images/vue_ext_ferme.jpeg

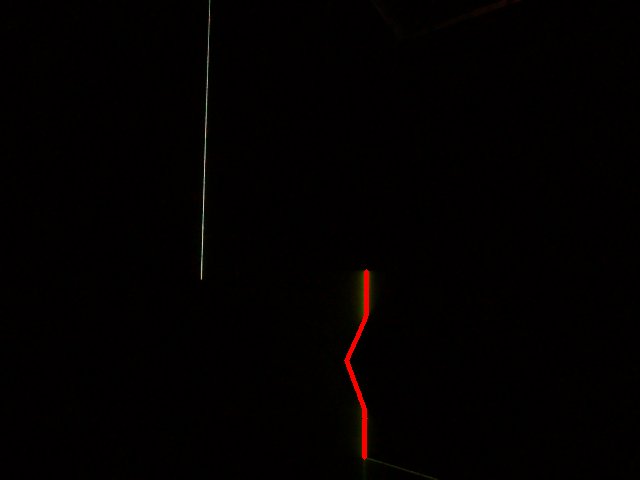
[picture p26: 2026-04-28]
docs/rapport/images/vue_camera.jpg

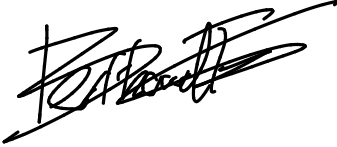
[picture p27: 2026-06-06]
docs/rapport/images/signaturetom.jpg

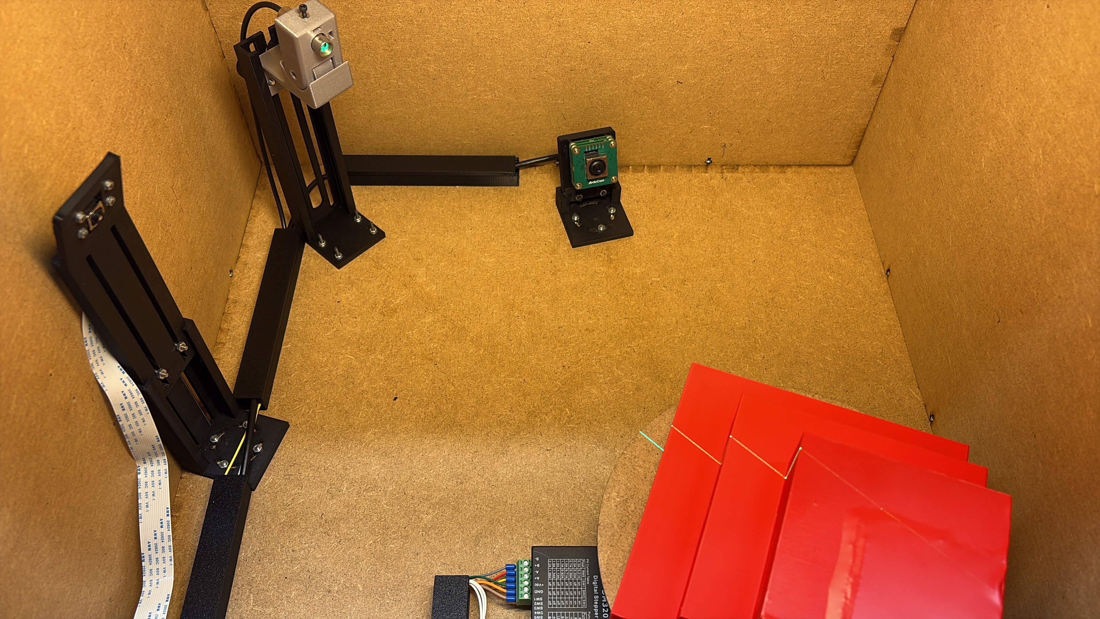
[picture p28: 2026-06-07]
docs/rapport/images/vue_int_finale.jpeg

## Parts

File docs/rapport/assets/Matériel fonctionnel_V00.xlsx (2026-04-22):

Liste de matériel fonctionnel
Cette liste contient le matériel fonctionnel de la machine double XY
Les schémas électriques seront dessinés sur la base de cette liste
 |  |  |  | Dernière mise à jour le :
 |  |  |  | Par:
Station | Fonction | Référence | Fournisseur | Information | Commandé
Plateu rotatif | Moteur rotatif | Generic 17HS3401
 | Contrôleur moteur | DM320T
Scan 3D | Laser (vert) | VLM-520-56 LPO-D45-F40
 | Caméra | Raspberry PI Camera Module 3
 | Capteur capot fermée | 125-250V |  | Petit commutateur 5A
HMI | Ecran tactile | Raspberry Pi Touch Display 2
Contrôleur | Raspberry pi | Raspberry Pi 4 Model B
Alimentation électrique | Connecteur d'alimentation (12Vdc) | Connecteur d'alim CC (Femelle) |  | Layette H 4
 | Interrupteur principal | KCD1-101 |  | Interrupteur à bascule
 | Convertisseur 12Vdc-5Vdc | LM2596 DC-DC / HW-411
 | Transpho. 12Vdc | Hama power 36w 5-15Vdc |  | Layette I 10

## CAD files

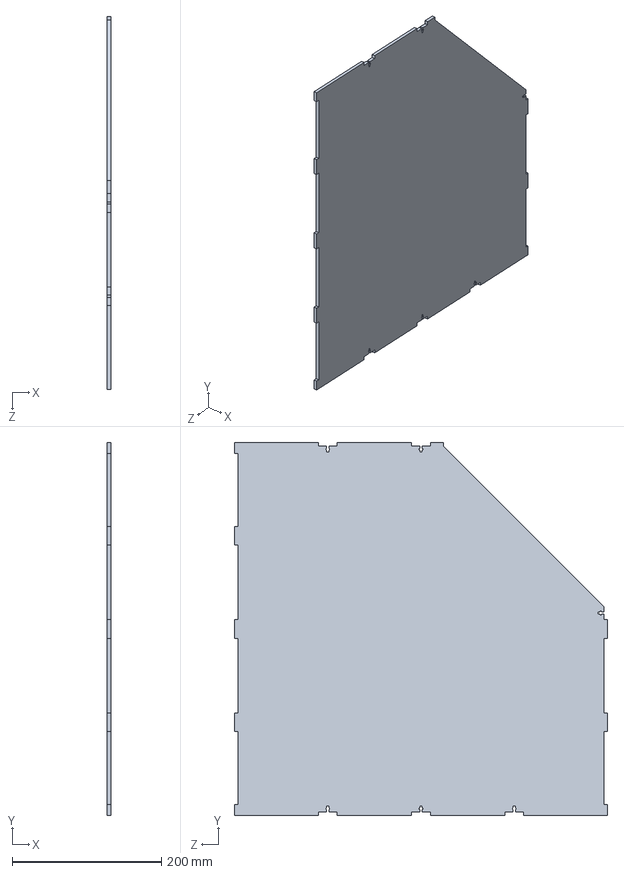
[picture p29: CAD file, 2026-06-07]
docs/conceptionmecanique/Cote_droit.SLDPRT
5.00 x 500.0 x 500.0 mm

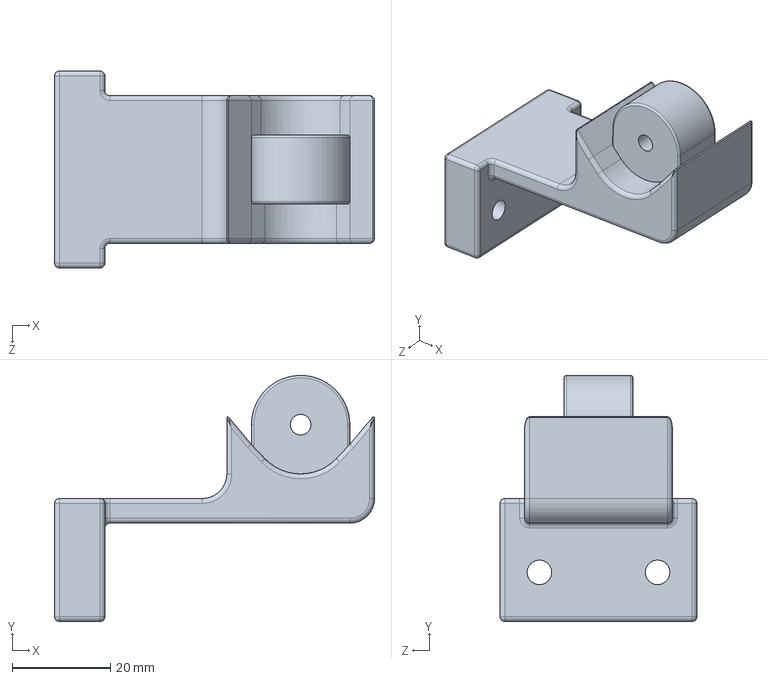
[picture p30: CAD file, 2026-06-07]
docs/conceptionmecanique/Support2_laser__V2.SLDPRT
65.0 x 50.0 x 40.0 mm

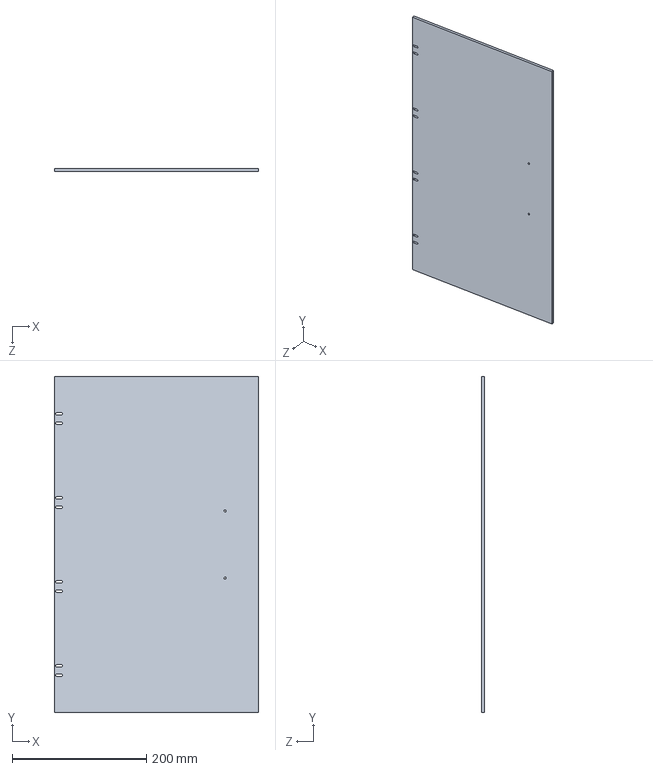
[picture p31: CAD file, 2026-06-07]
docs/conceptionmecanique/Porte.SLDPRT
304.0 x 500.0 x 5.00 mm

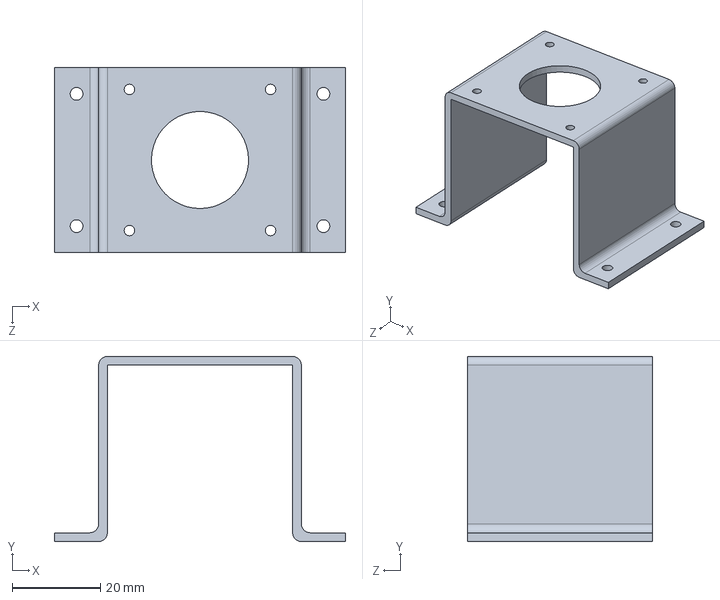
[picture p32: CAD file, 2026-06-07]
docs/conceptionmecanique/Support_moteur.SLDPRT
66.0 x 42.0 x 42.0 mm

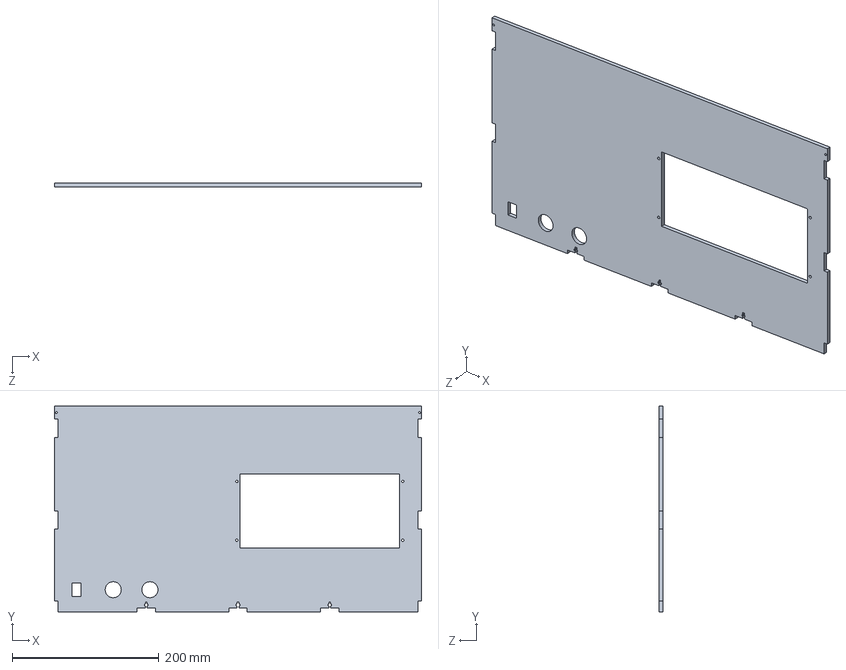
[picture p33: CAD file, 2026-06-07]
docs/conceptionmecanique/Avant.SLDPRT
500.0 x 280.0 x 5.00 mm

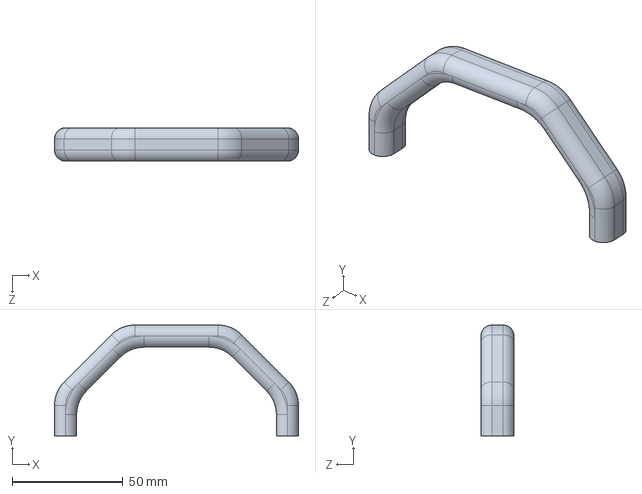
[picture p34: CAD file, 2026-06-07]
docs/conceptionmecanique/poignée.SLDPRT
110.0 x 50.0 x 15.0 mm

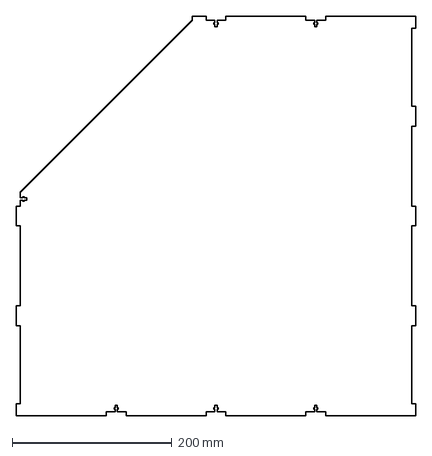
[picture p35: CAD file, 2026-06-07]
docs/conceptionmecanique/Cote_droit_VF.DXF
500.0 x 500.0 mm

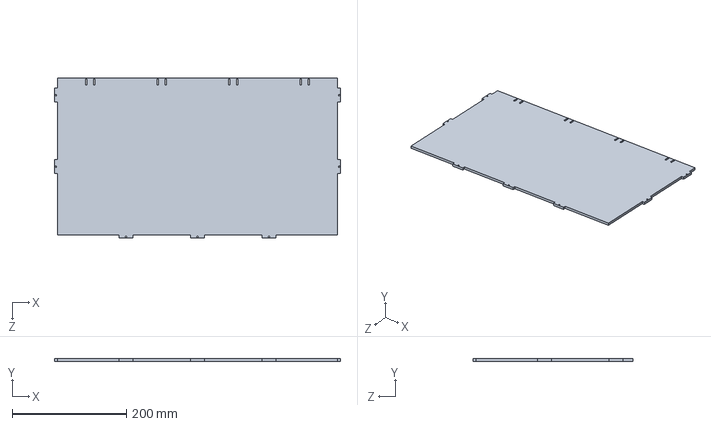
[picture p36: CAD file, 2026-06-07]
docs/conceptionmecanique/Dessus.SLDPRT
500.0 x 5.00 x 280.0 mm

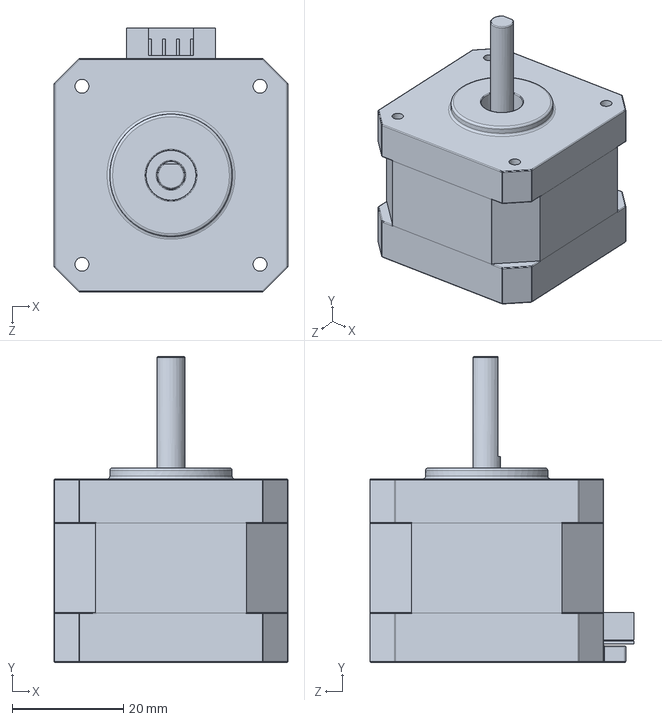
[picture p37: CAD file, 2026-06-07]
docs/conceptionmecanique/Moteur_pas_à_pas.SLDPRT
42.0 x 55.0 x 47.5 mm

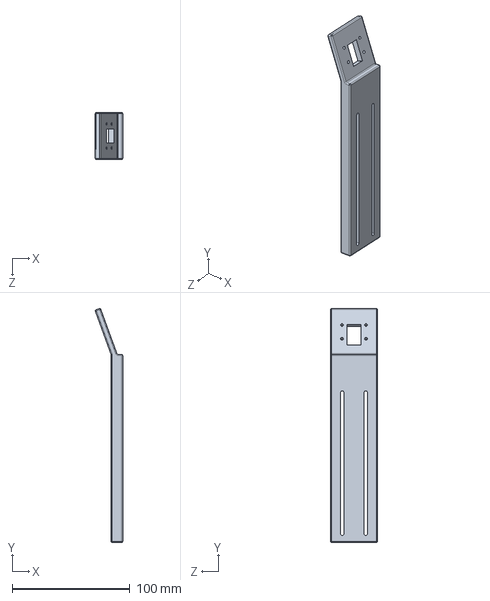
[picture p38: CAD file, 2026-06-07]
docs/conceptionmecanique/Support_camera_V2.SLDPRT
23.4 x 199.0 x 40.0 mm

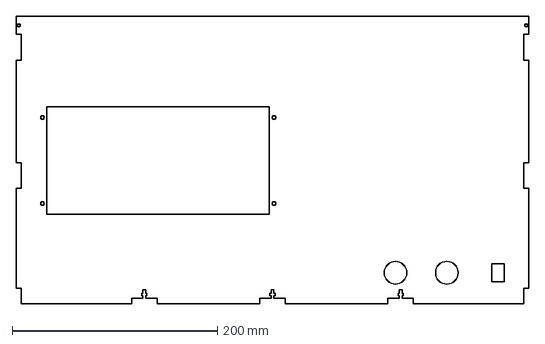
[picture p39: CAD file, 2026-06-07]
docs/conceptionmecanique/Avant_VF.DXF
500.0 x 280.0 mm

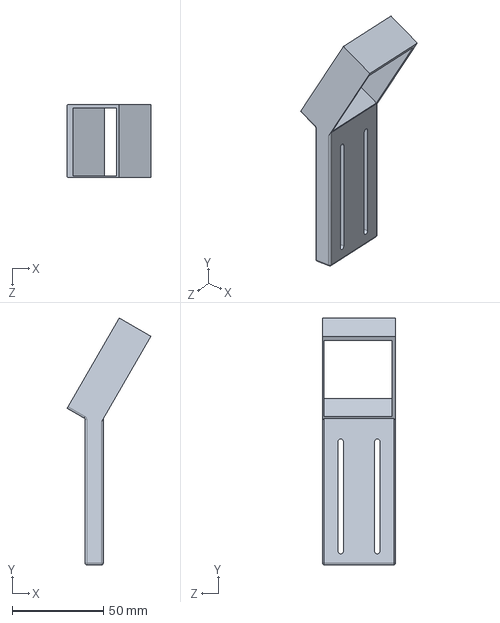
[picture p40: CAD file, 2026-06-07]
docs/conceptionmecanique/Support_camera2_V2.SLDPRT
45.8 x 135.0 x 40.0 mm

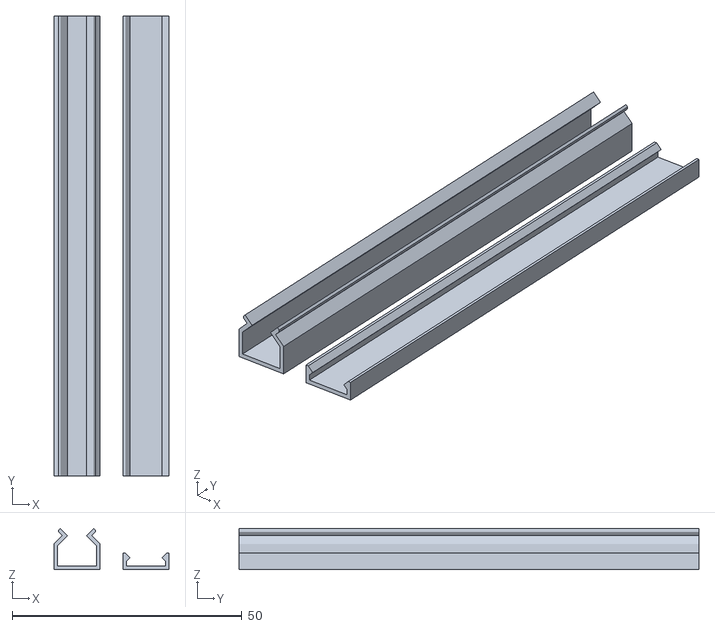
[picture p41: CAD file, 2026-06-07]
docs/conceptionmecanique/Cabletray_W10xH10xL100.stl
25.0 x 100.0 x 8.97

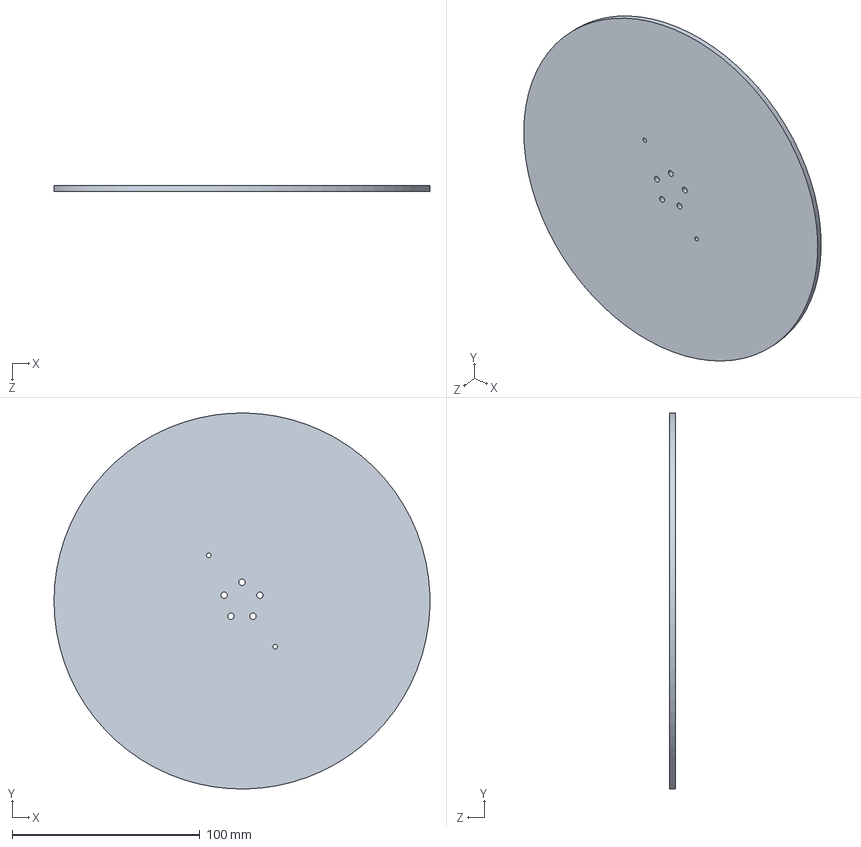
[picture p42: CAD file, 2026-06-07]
docs/conceptionmecanique/Plateau_rotatif.SLDPRT
200.0 x 200.0 x 3.00 mm

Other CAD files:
docs/conceptionmecanique/Assemblage_laser.SLDASM
docs/conceptionmecanique/Assemblage_support_camera1_laser.SLDASM
docs/conceptionmecanique/scanner_V2.SLDASM
docs/conceptionmecanique/Cote_gauche.SLDPRT
docs/conceptionmecanique/Base.DXF
docs/conceptionmecanique/Base.SLDPRT
docs/conceptionmecanique/Boite.SLDPRT
docs/conceptionmecanique/Cabletray_W10xH06xL100.stl
docs/conceptionmecanique/Cote_gauche_VF.DXF
docs/conceptionmecanique/Dessus.DXF
docs/conceptionmecanique/Fond.DXF
docs/conceptionmecanique/Fond.SLDPRT
docs/conceptionmecanique/Plateau_rotatif.DXF
docs/conceptionmecanique/Porte.DXF
docs/conceptionmecanique/Support2_laser__V2.STL
docs/conceptionmecanique/Support_base.SLDPRT
docs/conceptionmecanique/Support_base.STL
docs/conceptionmecanique/Support_camera_V2.STL
docs/conceptionmecanique/Support_ecran.SLDPRT
docs/conceptionmecanique/Support_ecran.STL
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

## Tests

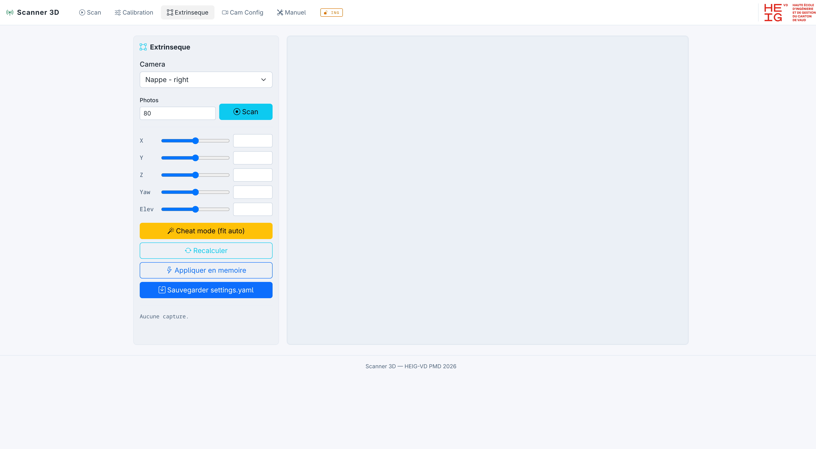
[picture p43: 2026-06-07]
docs/rapport/images/ui_calibration_extrinseque.png

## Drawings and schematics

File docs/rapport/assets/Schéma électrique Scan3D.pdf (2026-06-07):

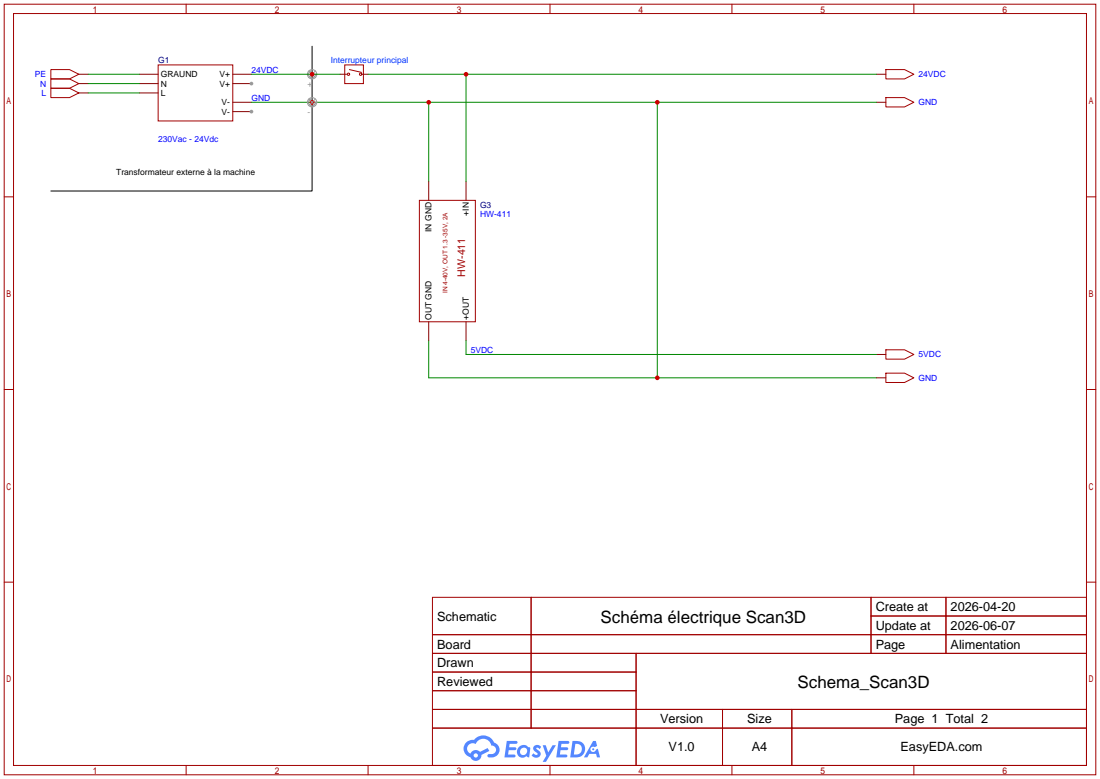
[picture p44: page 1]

Transformateur externe à la machine

IN GND OUT GND

Schematic | Schéma électrique Scan3D | Create at | 2026-04-20

Update at | 2026-06-07

Board | | Page | Alimentation
Drawn | | Schema_Scan3D
Reviewed

Version | Size | Page 1 Total 2
V1.0 | A4 | EasyEDA.com

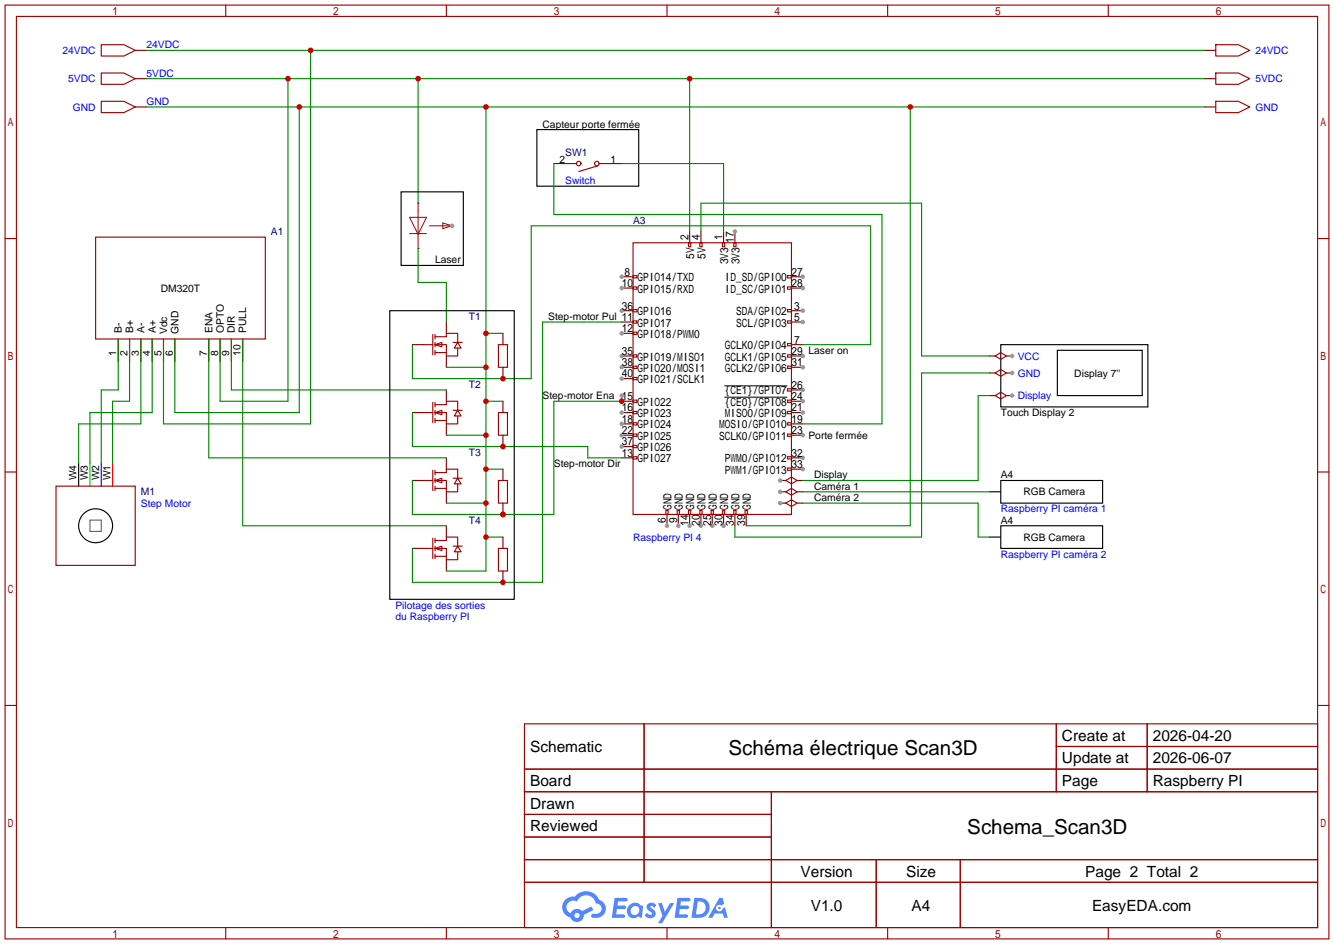
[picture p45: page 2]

Schematic | Schéma électrique Scan3D | Create at | 2026-04-20

Update at | 2026-06-07

Board | | Page | Raspberry PI
Drawn | | Schema_Scan3D
Reviewed

Version | Size | Page 2 Total 2
V1.0 | A4 | EasyEDA.com

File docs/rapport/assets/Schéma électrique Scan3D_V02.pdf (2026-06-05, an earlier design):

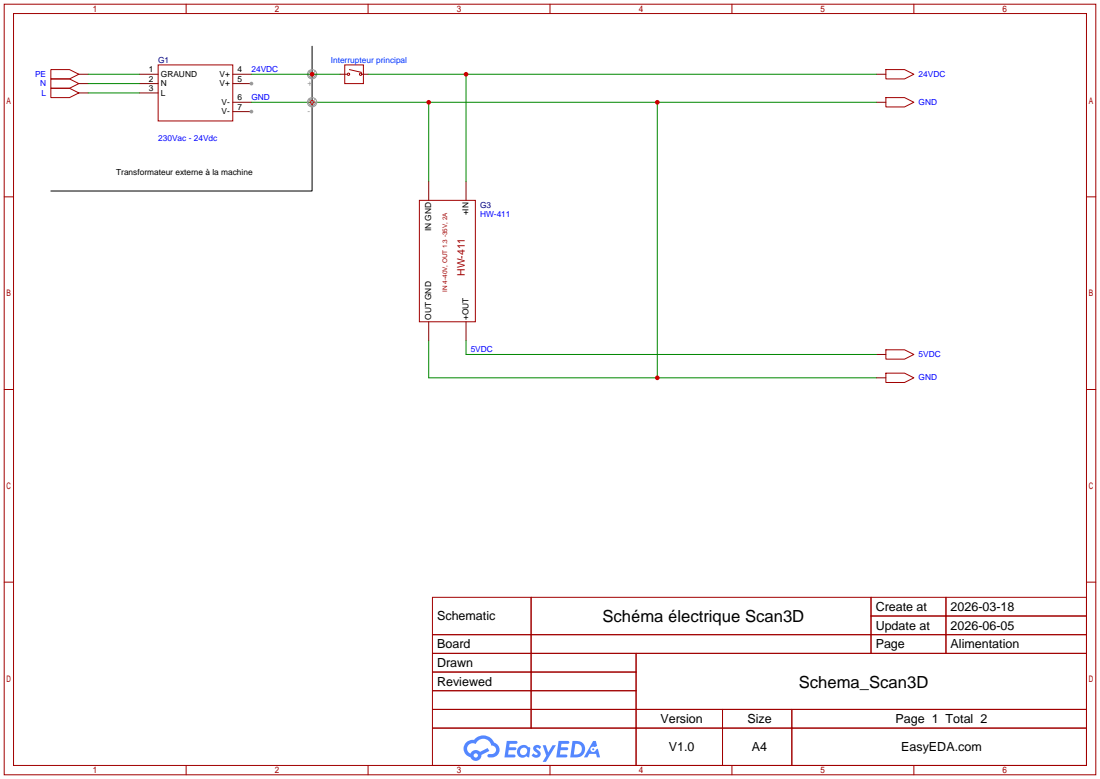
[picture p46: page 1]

Transformateur externe à la machine

IN GND OUT GND

Schematic | Schéma électrique Scan3D | Create at | 2026-03-18

Update at | 2026-06-05

Board | | Page | Alimentation
Drawn | | Schema_Scan3D
Reviewed

Version | Size | Page 1 Total 2
V1.0 | A4 | EasyEDA.com

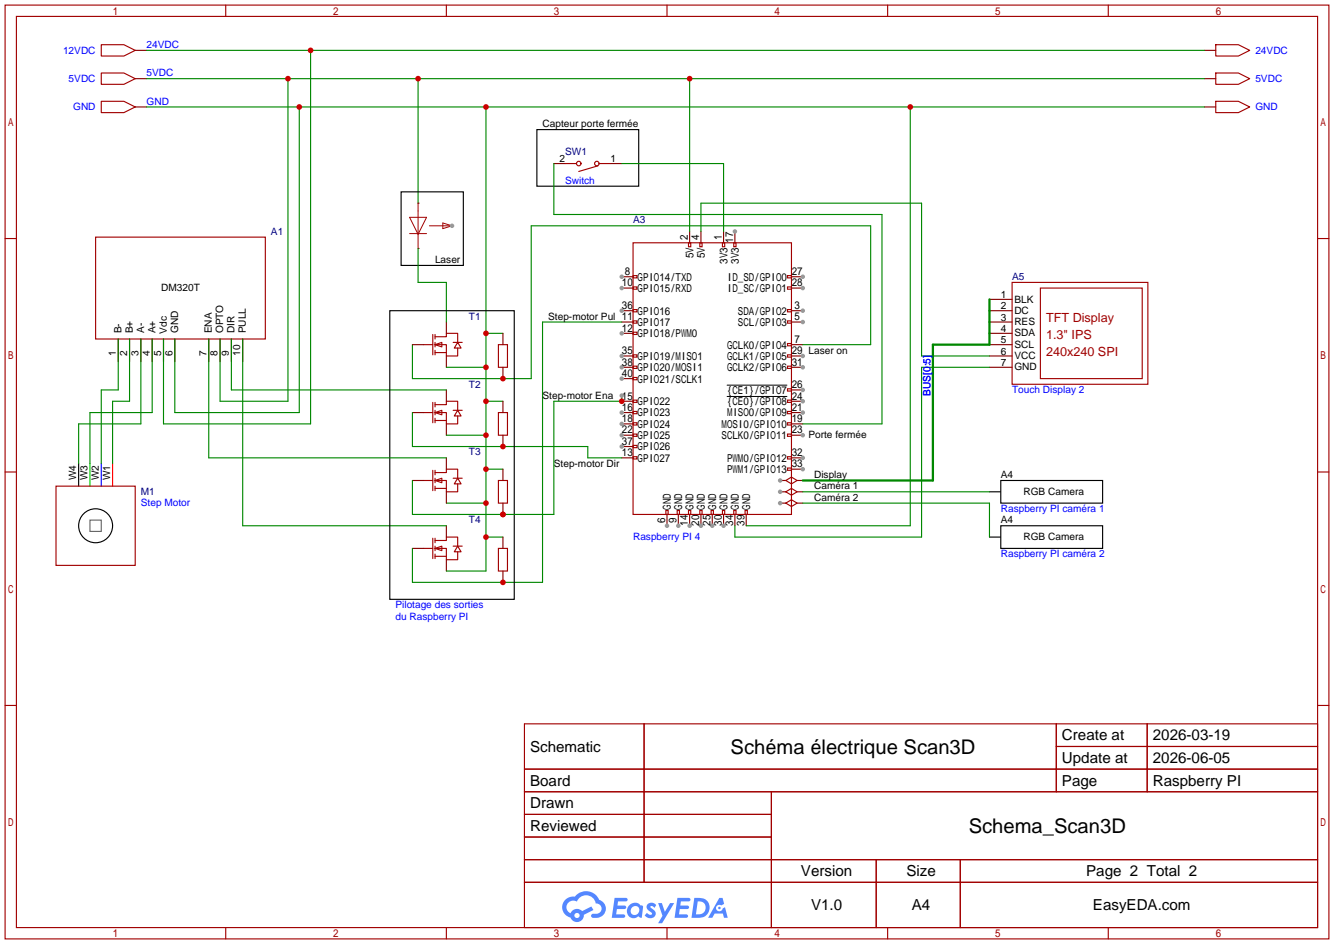
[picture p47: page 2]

Schematic | Schéma électrique Scan3D | Create at | 2026-03-19

Update at | 2026-06-05

Board | | Page | Raspberry PI
Drawn | | Schema_Scan3D
Reviewed

Version | Size | Page 2 Total 2
V1.0 | A4 | EasyEDA.com

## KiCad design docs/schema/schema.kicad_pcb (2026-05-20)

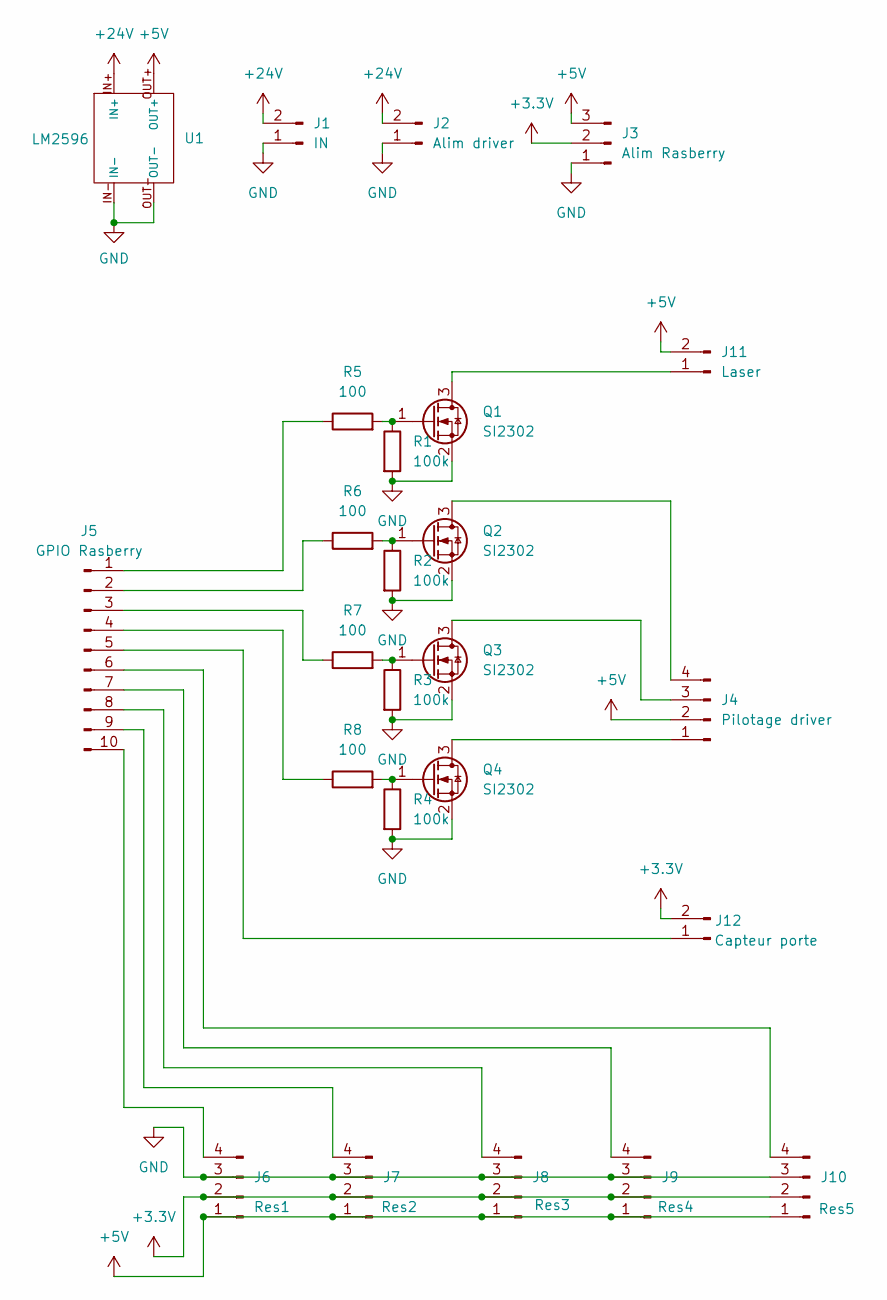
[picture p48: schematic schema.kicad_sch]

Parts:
J1: IN; PinHeader_1x02_P2.54mm_Vertical
J2: Alim driver; PinHeader_1x02_P2.54mm_Vertical
J3: Alim Rasberry; PinHeader_1x03_P2.54mm_Vertical
J4: Pilotage driver; PinHeader_1x04_P2.54mm_Vertical
J5: GPIO Rasberry; PinHeader_1x10_P2.54mm_Vertical
J6: Res1; PinHeader_1x04_P2.54mm_Vertical
J7: Res2; PinHeader_1x04_P2.54mm_Vertical
J8: Res3; PinHeader_1x04_P2.54mm_Vertical
J9: Res4; PinHeader_1x04_P2.54mm_Vertical
J10: Res5; PinHeader_1x04_P2.54mm_Vertical
J11: Laser; PinHeader_1x02_P2.54mm_Vertical
J12: Capteur porte; PinHeader_1x02_P2.54mm_Vertical
Q1, Q2, Q3, Q4: SI2302; SOT-23
R1, R2, R3, R4: 100k; R_1206_3216Metric
R5, R6, R7, R8: 100; R_1206_3216Metric
U1: LM2596; LM2596 module

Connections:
+3.3V: J3.2, J6.2, J7.2, J8.2, J9.2, J10.2, J12.2
+5V: J3.3, J4.2, J6.1, J7.1, J8.1, J9.1, J10.1, J11.2, U1.OUT+
+24V: J1.2, J2.2, U1.IN+
GND: J1.1, J2.1, J3.1, J6.3, J7.3, J8.3, J9.3, J10.3, Q1.2 (S), Q2.2 (S), Q3.2 (S), Q4.2 (S), R1.2, R2.2, R3.2, R4.2, U1.IN-, U1.OUT-
unnamed: J4.1, Q4.3 (D)
unnamed: J4.3, Q3.3 (D)
unnamed: J4.4, Q2.3 (D)
unnamed: J5.1, R5.1
unnamed: J5.2, R6.1
unnamed: J5.3, R7.1
unnamed: J5.4, R8.1
unnamed: J5.7, J9.4
unnamed: J5.8, J8.4
unnamed: J5.9, J7.4
unnamed: J5.10, J6.4
unnamed: J5.6, J10.4
unnamed: J11.1, Q1.3 (D)
unnamed: J5.5, J12.1
unnamed: Q1.1 (G), R1.1, R5.2
unnamed: Q2.1 (G), R2.1, R6.2
unnamed: Q3.1 (G), R3.1, R7.2
unnamed: Q4.1 (G), R4.1, R8.2

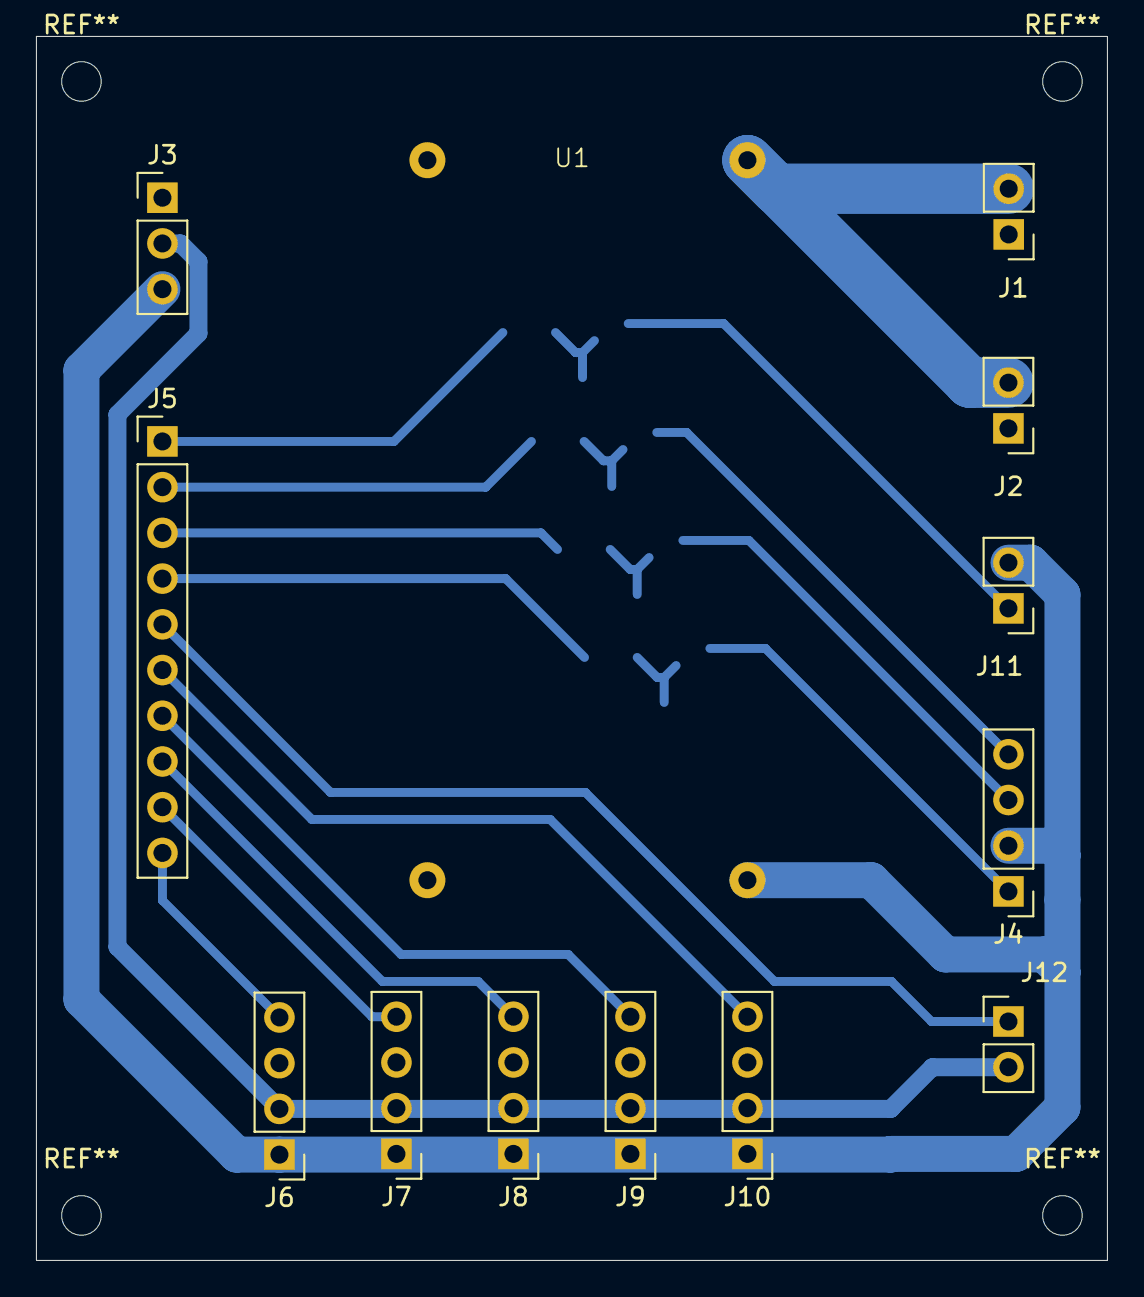
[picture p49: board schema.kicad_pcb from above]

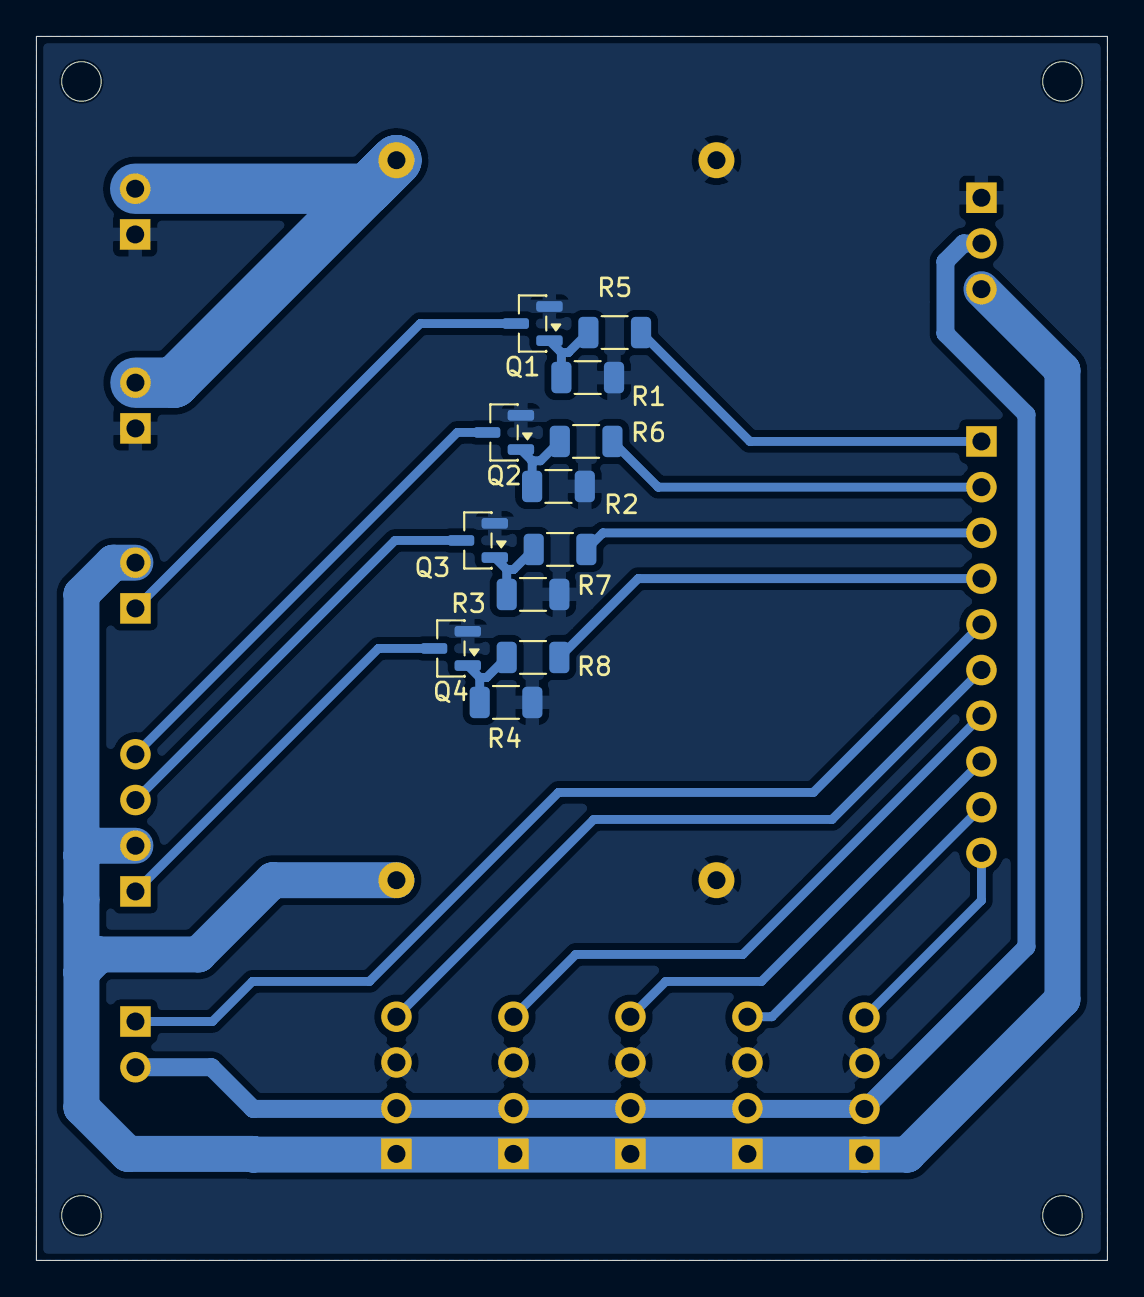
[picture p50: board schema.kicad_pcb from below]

Board: 2 copper layers, 59.5 x 68.0 mm, 25 parts (12 on the bottom side), 22 nets.

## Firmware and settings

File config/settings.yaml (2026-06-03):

# settings.yaml — Paramètres de scan du scanner3d-pmd
# Modifier ces valeurs selon votre configuration matérielle.
# Ne jamais committer les fichiers camera_intrinsics.yaml et laser_plane.yaml
# avec de vraies valeurs — utiliser les .example.yaml comme templates.

scan:
  n_steps: 100           # nombre de photos pour 360° (1 photo = steps_per_rev*microstepping/n_steps pas moteur)
  direction: clockwise      # sens de rotation : clockwise / counterclockwise
  exposure_calibration:
    enabled: true
    sample_count: 3
    angle_step_deg: 30.0
    target_median_width_px: 6.0
    tolerance_width_px: 1.0
    max_iterations: 4
    min_exposure_us: 200
    max_exposure_us: 60000
    max_adjust_factor: 3.0

camera:
  resolution: [640, 480]    # [width, height] en pixels (mock: 640x480 = résolution de calibration)
  mock_shape: cube            # forme simulée par le mock : cube uniquement
  exposure_us: 1000         # temps d'exposition en microsecondes (court = ligne laser nette)
  gain: 1.0                 # gain analogique (faible = moins de bruit)
  awb_mode: off             # balance des blancs : off (fixe) pour cohérence entre frames
  awb_gains: [0.5, 1.0]    # gains rouge/bleu — rouge bas pour supprimer reflets parasites

cameras:
  # Configuration multi-camera cible: camera droite Pi + camera gauche USB.
  # Les chemins pointent vers des fichiers calibres separes par camera.
  - id: right
    display_name: Nappe
    type: pi
    resolution: [640, 480]
    mock_shape: cube
    exposure_us: 5000
    gain: 1
    calibration_exposure_us: 20000
    calibration_gain: 4
    lens_position: 2.7
    laser_threshold: 44
    laser_sampling:
      x_stride: 1
      y_stride: 2
    laser_mask:
      - [[412, 271], [412, 480], [151, 480], [153, 454]]
      - [411, 0, 640, 480]
      - [0, 451, 414, 480]
      - [0, 0, 111, 455]
    awb_mode: off
    awb_gains: [0.5, 1.0]
    intrinsics_path: config/camera_intrinsics_right.yaml
    extrinsics_path: config/camera_extrinsics_right.yaml
    extrinsics:
      # Rough measured pose in the shared platform frame:
      # origin = turntable center at top surface.
      # +Z follows the laser axis from the laser toward the turntable center.
      # +X points right when looking from the laser toward the turntable.
      # +Y is vertical up and is the turntable rotation axis.
      position_mm: [120.300, 125.700, -254.000]
      # Mechanical optical-axis angles:
      # angle_camera_laser_deg = yaw in XZ plane, from +Z toward +X.
      # angle_planxz_camera_deg = elevation from the XZ plane.
      angle_camera_laser_deg: -25.400
      angle_planxz_camera_deg: -20.100
      up_mm: [0.0, 1.0, 0.0]
  - id: left
    display_name: USB Arducam
    type: usb
    device_index: 2
    device_path: /dev/video2
    backend: CAP_V4L2
    # Arducam B0475 reports only YUYV modes on this Raspberry Pi.
    # Supported sizes: 1280x720, 1920x1080, 2312x1736, 3840x2160, 4624x3472, 9248x6944.
    pixel_format: YUYV
    # High-resolution YUYV frames are heavy on USB; keep flush low to reduce bus load.
    flush_frames: 1
    # USB cameras can re-enumerate slowly on Raspberry Pi. These retries avoid
    # losing the Arducam after a short /dev/video2 disappearance.
    open_retries: 5
    open_retry_delay_s: 0.7
    reconnect_retries: 5
    reconnect_retry_delay_s: 0.4
    device_wait_s: 3.0
    startup_frame_check: true
    v4l2_exposure_scale_us: 100
    resolution: [1920, 1080]
    mock_shape: cube
    exposure_us: 8000
    # V4L2 gain range reported by this camera: 100..1494.
    gain: 100
    calibration_exposure_us: 30000
    calibration_gain: 100
    focus_absolute: 500
    laser_threshold: 70
    laser_sampling:
      x_stride: 3
      y_stride: 4
    laser_mask:
      - [[0, 434], [672, 439], [616, 1069], [0, 1080]]
      - [[0, 438], [675, 441], [873, 0], [0, 0]]
      - [[1488, 1080], [1377, 0], [1920, 0], [1920, 1080]]
      - [550, 1065, 1500, 1080]
    intrinsics_path: config/camera_intrinsics_left.yaml
    extrinsics_path: config/camera_extrinsics_left.yaml
    extrinsics:
      # Rough measured pose in the shared platform frame:
      # origin = turntable center at top surface.
      # +Z follows the laser axis from the laser toward the turntable center.
      # +X points right when looking from the laser toward the turntable.
      # +Y is vertical up and is the turntable rotation axis.
      position_mm: [-161.500, -22.800, -264.800]
      # Mechanical optical-axis angles:
      # angle_camera_laser_deg = yaw in XZ plane, from +Z toward +X.
      # angle_planxz_camera_deg = elevation from the XZ plane.
      angle_camera_laser_deg: 32.800
      angle_planxz_camera_deg: 19.600
      up_mm: [0.0, 1.0, 0.0]
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

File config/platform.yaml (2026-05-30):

# platform.yaml - Calibration plateforme

steps_per_revolution: 200   # pas moteur pour 360 degres, sans microstepping
microstepping: 16            # facteur de microstepping utilise
degrees_per_step: 0.1125    # = 360 / (steps_per_revolution * microstepping)

# Repere plateforme:
# - origine: centre du plateau a ras de la surface
# - +Z: axe du laser, du laser vers le centre du plateau
# - +X: droite quand on regarde le plateau depuis le laser
# - +Y: hauteur, axe de rotation du plateau
rotation_axis: [0.0, 1.0, 0.0]
rotation_axis_point_mm: [0.0, 0.0, 0.0]

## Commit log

2026-04-22 add assets
    [Matériel fonctionnel_V00.xlsx, Planning.xlsx]
2026-04-23 debug work
    [frame_replay_20260423_150438_cloud.ply, frame_replay_20260423_150512.stl, frame_replay_20260423_150512_cloud.ply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]
2026-04-28 docs: amélioration chapitre conception électronique et alimentation
    - Ajout nouvelle section 3.2 sur l'alimentation électrique avec schéma
    - Ajout subsection 3.3.1 sur l'étage de commande des GPIO avec explication technique
    - Mise à jour des signaux du driver moteur (Ena, Dir, Pull au lieu de Step/Dir)
    - Modification interface écran: DSI au lieu de HDMI/USB
    - Retrait LEDs de la table des composants (signalisation déléguée à l'état)
    - Renommage interface locale de 'Écran tactile 7 pouces' à 'Pi Touch Display 2'
    - Clarification du choix technique du driver DM320T
    - Correction de plusieurs références de numérotation des figures et sections
    - Ajout pages de numérotation (mainte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
2026-04-28 move image and modify gitignore
    [bobine.ply, bobine.stl, carre.ply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]
2026-04-28 correction dans la présentation
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2026-05-06 Meilleur interface pour la calibration de la distortion de la lentille
2026-05-06 Add KiCAD Schema
    [schema.kicad_pcb, schema.kicad_sch]
2026-05-07 WIP: Schema
    [schema.kicad_sch]
2026-05-13 Draw PCB schematic
    [schema.kicad_pcb, schema.kicad_sch]
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2026-05-20 Update PCB files
    [schema.kicad_pcb, schema.kicad_sch]
2026-05-21 Add PCB connector schema
2026-05-21 scanner: add dual camera pipeline
2026-05-21 interface: add dual camera scan artifacts viewer
2026-05-23 Ajout de la procédure de connexion et d'exécution dans le fichier connection_procedure.md
2026-05-23 Ajout de la procédure de connexion et d'exécution pour Windows.
2026-05-23 interface: prepare double camera scan workflow
2026-05-23 interface: add camera config tuning page
2026-05-23 hardware: improve usb camera runtime controls
2026-05-23 hardware: harden usb camera v4l2 controls
2026-05-23 config: set tuned double camera parameters
2026-05-23 hardware: tolerate delayed usb camera startup
2026-05-23 processing: simplify laser line extraction
2026-05-24 hardware: improve USB camera recovery
2026-05-24 processing: scope background crop to camera
2026-05-24 processing: remove obsolete background filter
2026-05-24 interface: add visual camera mask editor
2026-05-24 interface: support multiple polygon camera masks
2026-05-24 processing: snap camera masks to image edges
    [test_processing.py]
2026-05-24 config: add calibrated camera masks
2026-05-24 processing: reduce mask edge snap tolerance
    [test_processing.py]
2026-05-24 config: update right camera trapezoid mask
2026-05-24 config: update left camera right-edge mask
2026-05-24 docs: update double-camera setup todo
2026-05-24 interface: add per-camera calibration workflow
2026-05-24 config: set USB camera to 1080p
2026-05-24 config: update USB camera mask
2026-05-24 interface: add camera calibration exposure controls
2026-05-24 docs: add printable calibration checkerboard
2026-05-24 calibration: report camera calibration errors
    [camera.py]
2026-05-24 config: add camera intrinsics calibration
2026-05-24 config: reduce right camera scan exposure
2026-05-24 config: track camera intrinsics files
2026-05-24 config: clarify platform coordinate frame
2026-05-24 calibration: support vertical laser reference board
2026-05-24 interface: guide dual-camera laser calibration
2026-05-24 config: add calibrated laser planes
2026-05-24 docs: update setup calibration checklist
2026-05-25 calibration: use shared global laser plane
2026-05-25 config: update global laser plane calibration
2026-05-25 Try theorical laser plane
2026-05-25 processing: add laser line sampling
2026-05-25 calibration: add checkerboard extrinsics workflow
2026-05-25 calibration: guard extrinsics pose selection
2026-05-25 calibration: add turntable extrinsics calibration
2026-05-25 calibration: automate turntable extrinsics captures
2026-05-25 calibration: remove extrinsics calibration workflow
2026-05-25 calibration: support mechanical angle extrinsics
2026-05-25 calibration: add ArUco cube extrinsics workflow
2026-05-25 calibration: auto-select ArUco cube layout
2026-05-25 calibration: estimate ArUco cube angle offset
2026-05-25 Revert "calibration: auto-select ArUco cube layout"
    This reverts commit b35d39b862c626702fe6430db8cf9b53e6b2a0f1.
2026-05-25 Revert "calibration: estimate ArUco cube angle offset"
    This reverts commit bc08a64754e82f805513dc43590bdfa3b0723649.
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2026-05-26 fix: correct camera Y-axis (down vector) in extrinsics rotation
    The cross(up, forward) fix for the right vector was incomplete —
    cross(forward, right) produced world UP instead of DOWN for the
    camera Y-axis. Changed to cross(right, forward) so the camera-to-
    platform matrix correctly maps OpenCV Y-down to platform Y-up
    (det(R)=-1, which is expected for this reflection).
    [test_calibration.py, test_multi_camera.py]
2026-05-26 interface: add extrinsics cheat mode auto-fit between cameras
2026-05-26 interface: make cheat mode optimize both cameras from cached extracted points
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2026-05-28 processing: fuse dual-camera profiles by continuous segments per angle
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2026-05-30 hardware: make LEDs optional and disable them in settings
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2026-05-30 safety: force laser off immediately on door open
2026-05-30 reconstruction: switch to single flat bottom cap and enable flat_caps
2026-05-30 reconstruction: place bottom cap on world-Y plane (XZ footprint)
2026-05-31 interface: thème clair, assets hors-ligne, mode ingénierie & outillage
    - UI en thème clair responsive (desktop / mobile / kiosk), pilotée par variables CSS
    - Assets vendorisés (Bootstrap, icônes, polices, Three.js) dans static/vendor/ :
    fonctionnement hors-ligne + cache navigateur long, plus aucune dépendance CDN
    - Latence : qualité JPEG des aperçus live réduite, en-têtes no-store, polling
    caméra/tuning/processing auto-réamorcé (img.onload) pour ne pas saturer le Pi
    - Mode ingénierie : Calibration / Extrinsèque / Cam Config / Manuel verrouillés
    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
2026-05-31 interface: filter extrinsics fit points by 2D vertical-angle gate
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2026-06-02 scan: iterate exposure calibration until tolerance
    [settings.yaml]
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2026-06-05 ajout image, buget et planning
    [Planning.xlsx]
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2026-06-07 ajout image UI final, corriger des malcomprension
2026-06-07 Clean old files
    [frame_replay_20260423_150438_cloud.ply, frame_replay_20260423_150512.stl, frame_replay_20260423_150512_cloud.ply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]
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2026-06-07 2eme partie chapitre 06 Ok, Attention il faut encore réglé le nettoyage que hadien a fait !
2026-06-07 fais du trie
    [bobine.ply, bobine.stl, carre.ply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]
2026-06-07 changement de caisson par boite et ajout des gravure
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2026-06-07 ajout conception mec
    [Assemblage_laser.SLDASM, Assemblage_support_camera1_laser.SLDASM, Avant.SLDPRT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]
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2026-10-15 Retrait des .DS_Store ; liens GitHub de l'équipe
